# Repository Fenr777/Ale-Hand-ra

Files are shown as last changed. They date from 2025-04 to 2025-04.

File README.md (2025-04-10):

# Ale-HAND-ra: An Open-Source, Low-Cost Humanoid Robotic Hand

**Ale-HAND-ra** is an open-source humanoid robotic hand designed to be affordable, accessible, and highly functional. It leverages digital fabrication techniques like 3D printing to replicate the dexterity and movement of a human hand using low-cost materials. As an open-source initiative, Ale-HAND-ra invites collaboration and customization from the robotics community for educational, prosthetic, or research applications.

<p align="center">
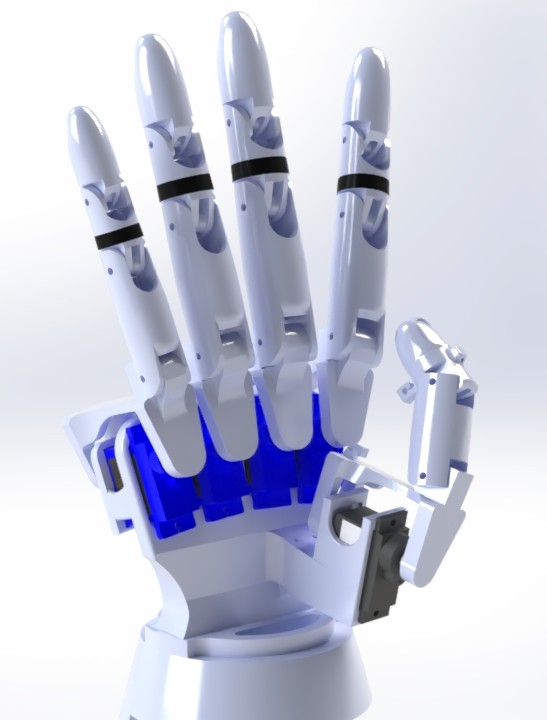
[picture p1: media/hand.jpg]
  
</p>

---

## Table of Contents

- [Ale-HAND-ra: An Open-Source, Low-Cost Humanoid Robotic Hand](#ale-hand-ra-an-open-source-low-cost-humanoid-robotic-hand)
  - [Table of Contents](#table-of-contents)
  - [About the Project](#about-the-project)
  - [Features](#features)
  - [Getting Started](#getting-started)
  - [Estimated Costs](#estimated-costs)
  - [Repository Structure](#repository-structure)
  - [Contributing](#contributing)
  - [License](#license)

---

## About the Project

Ale-HAND-ra addresses the lack of accessible, open-source robotic hands that emulate human functionality. By combining biomechanical analysis with cost-effective 3D printing, this hand achieves 20 degrees of freedom, enabling precise grasping and manipulation of objects of up to 350 grams. Its modular design and use of affordable components—like SG90, EMAX ES08MD II, and MG996R servomotors—make it an ideal platform for hobbyists, students, and researchers.

<p align="center">
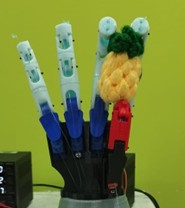
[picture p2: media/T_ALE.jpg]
  
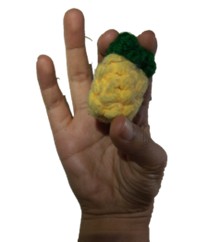
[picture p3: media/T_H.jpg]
  
</p>

---

## Features

- **20 Degrees of Freedom**: Closely mimics human hand biomechanics, supporting flexion, extension, abduction, adduction, and wrist pronation/supination.
- **Modular Design**: Easy to customize, repair, or modify individual components (palm, fingers, forearm).
- **Precise Control**: Powered by an ESP32 microcontroller and PCA9685 PWM module, with wireless control via the Blynk platform.
- **Low-Cost Fabrication**: Built using 3D-printed parts and affordable servomotors, optimized for accessibility.
- **Open-Source**: Fully documented design and code, encouraging community contributions.
  
<p align="center">
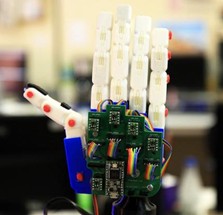
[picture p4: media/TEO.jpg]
  
</p>

---

## Getting Started

To build your own Ale-HAND-ra, follow these steps:

1. **Review the Build Guide**: See [`documentation/build_guide.md`](./documentation/build_guide.md) for detailed assembly instructions.
2. **Gather Materials**: Check the List of Materials in for required components.
3. **3D Print the Parts**: Use the files from [`design_files/ready_to_print_files/`](./design_files/ready_to_print_files) to 3D print all the hand parts.
4. **Assemble the Hand**: Follow the step-by-step instructions in the build guide.
5. **Upload the Code**: Use the Arduino code at [`code/ALEHANDRA.ino`](./code/ALEHANDRA.ino) to test your hand!

**Prerequisites**:
- 3D printer (FDM or SLA recommended, but not necessary)
- Basic electronics skills (soldering, wiring)
- Arduino programming knowledge

<p align="center">
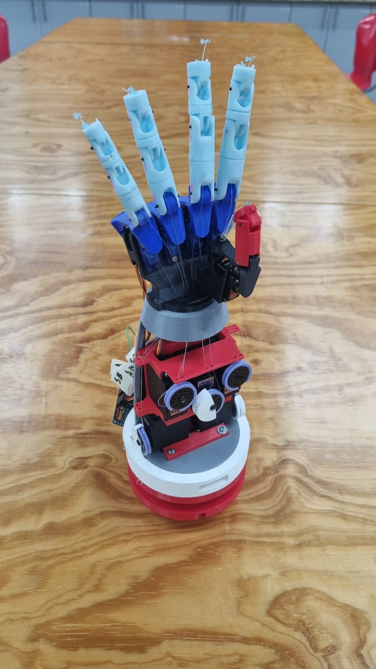
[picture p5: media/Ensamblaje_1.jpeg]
  
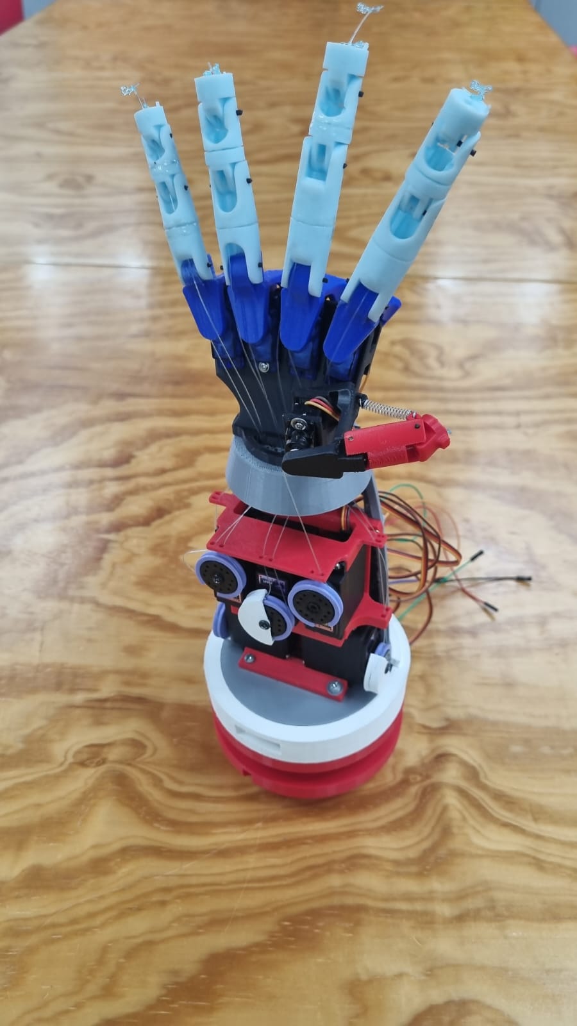
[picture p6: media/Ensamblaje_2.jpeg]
  
</p>

---

## Estimated Costs

Ale-HAND-ra is designed to be cost-effective. Here’s a breakdown of the cost per hand manufactured:

| Description | Quantity | Subtotal ($) | Comments |
|---|---|---|---|
| 3D Printing (Resin) | 264 minutes  | 21.33 | Price per FABLAB UNITEC |
| 3D Printing (PLA) | 210 minutes  | 10.18 | Price per FABLAB UNITEC |
| EMAX ES08MD II Servomotor | 1 | 11.72 | N/A |
| SG90 Servomotors | 4 | 26.67 | N/A |
| MG996R Servomotors | 5 | 58.59 | N/A |
| ESP32 Microcontroller | 1 | 16.97 | N/A |
| PCA9685 Servo Controller | 1 | 10.42 | N/A |
| Dupont Cables (Female-Female, Male-Male, Male-Female) | 1 | 10.10 | N/A |
| Fishing Nylon | 1 | 1.90 | N/A |
| **TOTAL ($)** | | **167.88** | |

---

## Repository Structure

- **`design_files/`**: 3D models for printing and modification.
  - `ready_to_print_files/`: Ready-to-print files.
  - `solidworks/`: Native SolidWorks files.
- **`code/`**: Code for testing hand movement.
- **`documentation/`**: Extra documentation.
- **`media/`**: Visuals for documentation and README.

---

## Contributing

We welcome contributions to enhance Ale-HAND-ra! To get involved:
- Report bugs or suggest features via GitHub Issues.
- Fork the repo and try it out!
- Share your builds or modifications with the community.
- Leave a star if you like our work!

---

## License

This project is licensed under the [MIT License](LICENSE), allowing free use, modification, and distribution with proper attribution.

---

<p align="center">
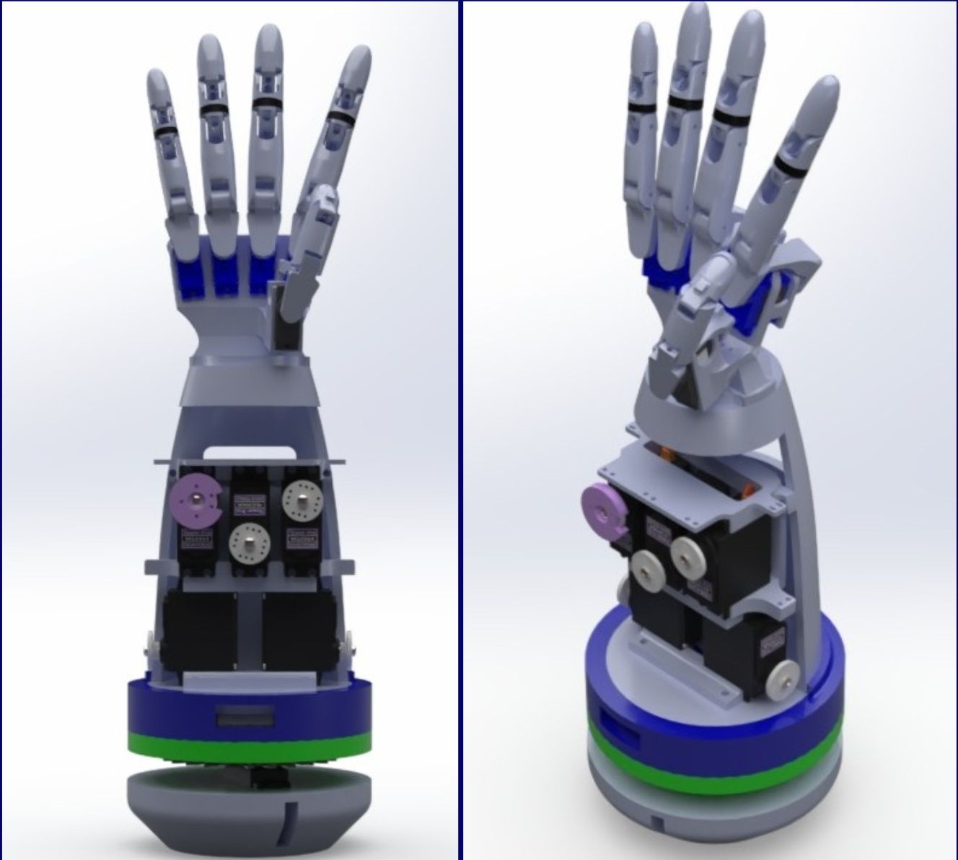
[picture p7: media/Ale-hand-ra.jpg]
  
</p>

*Multiview Ale-HAND-ra*

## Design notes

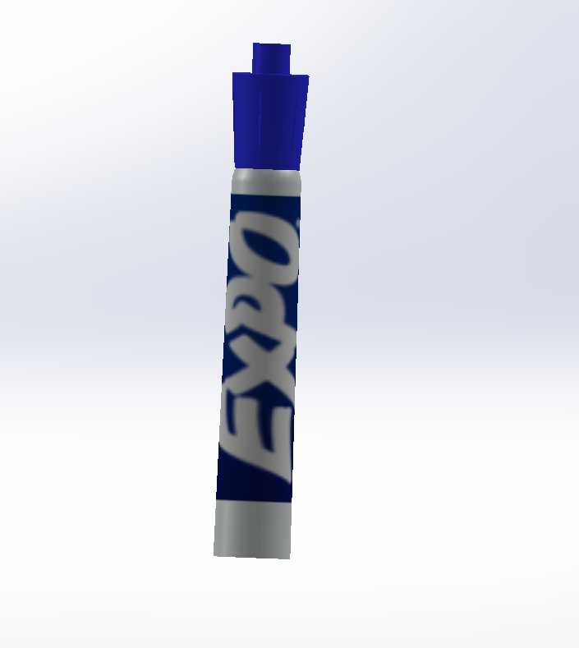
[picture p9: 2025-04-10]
design_files/solidworks/expo-marker-1.snapshot.2/Renderings/Untitled.png

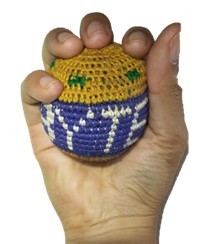
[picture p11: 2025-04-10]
media/EP_H.jpg

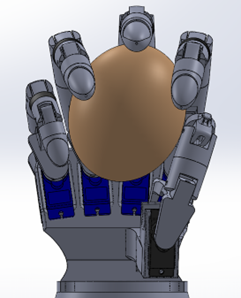
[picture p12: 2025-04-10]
media/E ALE SW.png

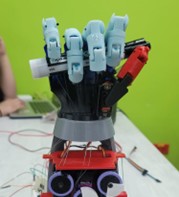
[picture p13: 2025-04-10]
media/DP_ALE.jpg

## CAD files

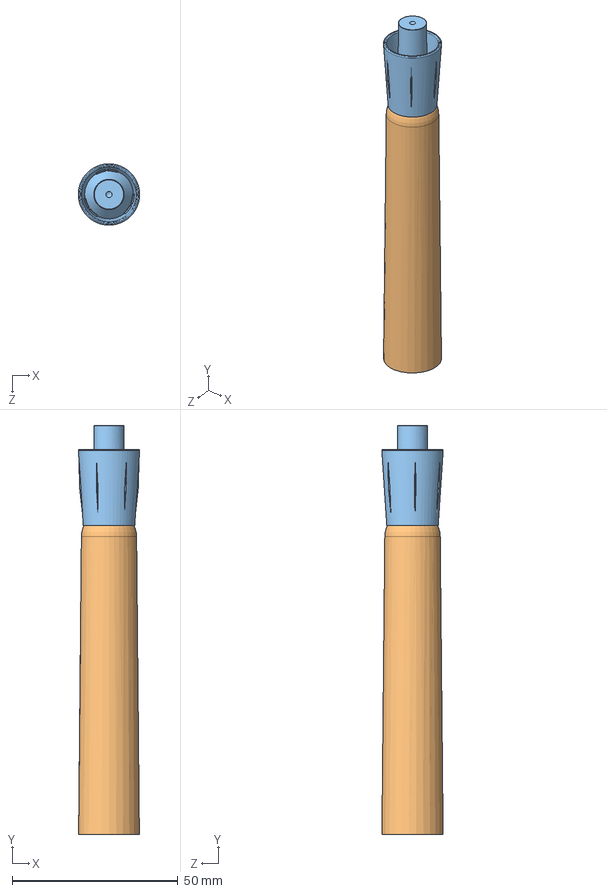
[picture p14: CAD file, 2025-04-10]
design_files/solidworks/expo-marker-1.snapshot.2/EMF.SLDASM
18.5 x 123.5 x 18.5 mm
tip
EARTH
Expo Marker Cap
marker bottom
ink

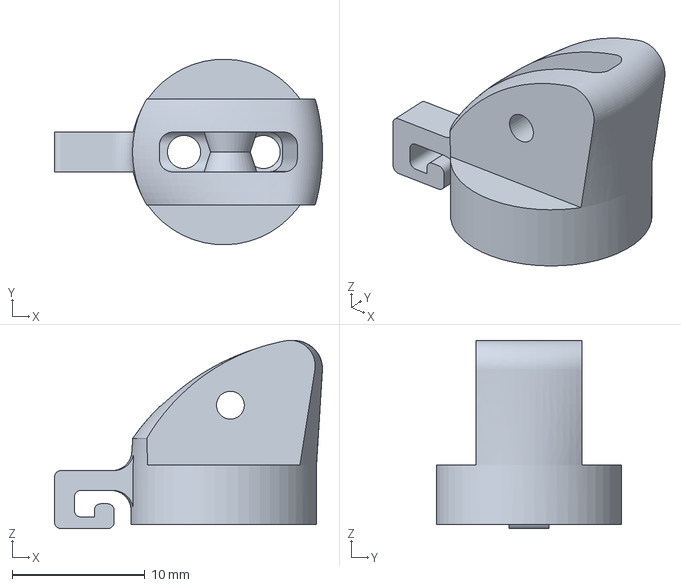
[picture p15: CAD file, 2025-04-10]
design_files/ready_to_print_files/Pulgar_2_FDM.3MF
20.2 x 14.0 x 14.2 mm

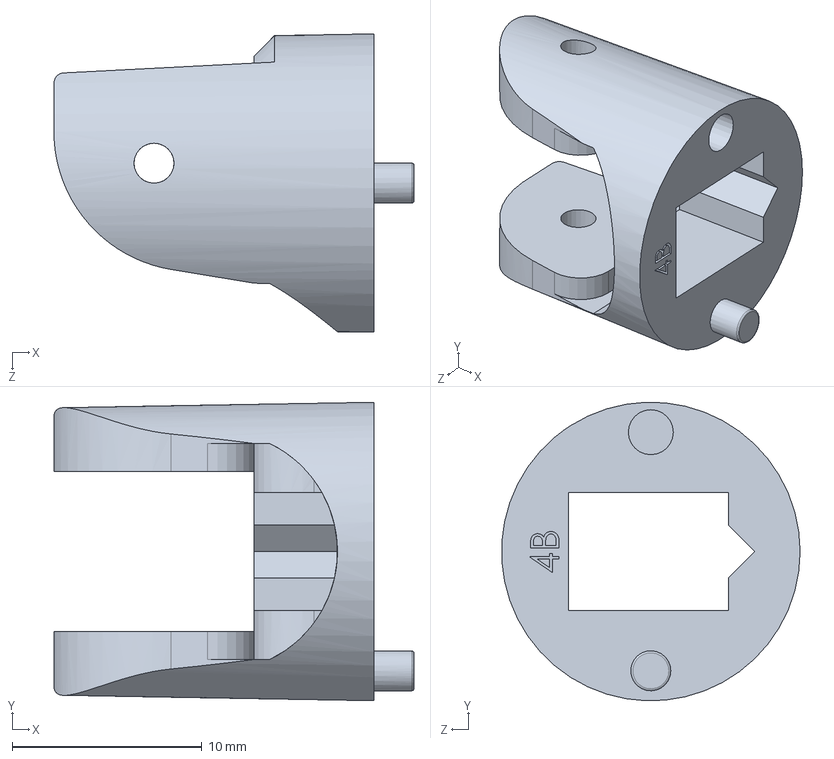
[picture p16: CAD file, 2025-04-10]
design_files/solidworks/DEDO_MEDIO/B Falange 3-6.SLDPRT
19.0 x 15.7 x 15.7 mm

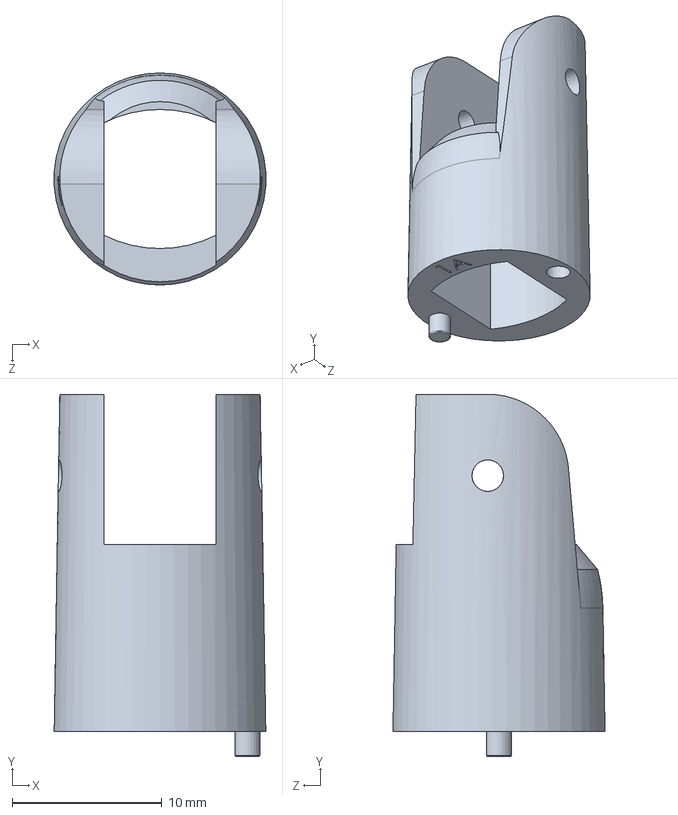
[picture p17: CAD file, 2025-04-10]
design_files/solidworks/DEDO_MEÑIQUE/A Falange 3-4.SLDPRT
14.1 x 24.2 x 14.2 mm

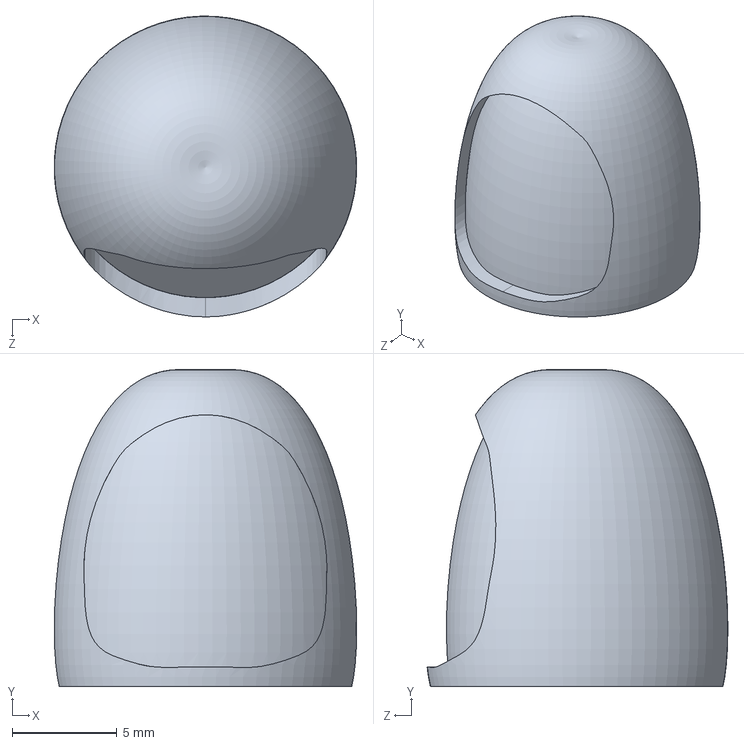
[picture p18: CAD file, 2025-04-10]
design_files/solidworks/DEDO_PULGAR/Uña_pulgar.SLDPRT
14.5 x 15.2 x 14.4 mm

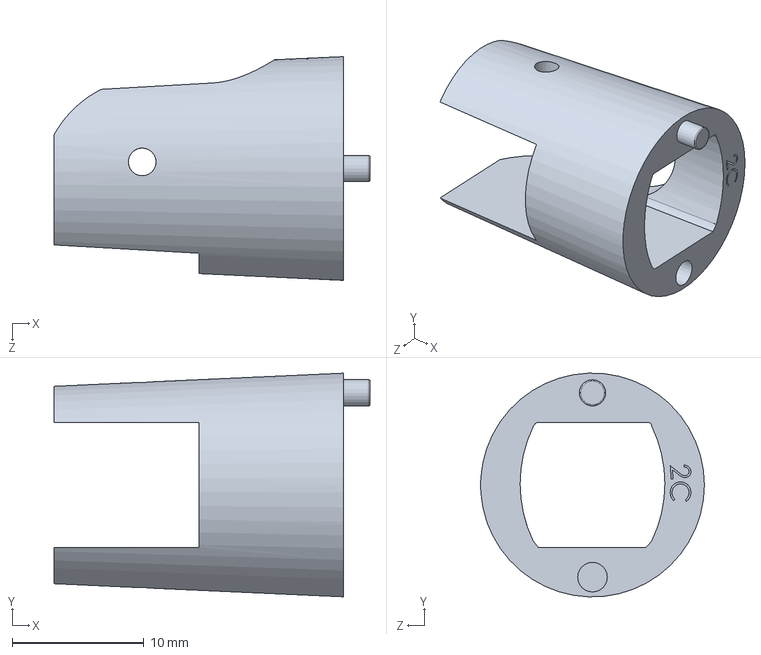
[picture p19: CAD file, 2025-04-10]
design_files/solidworks/DEDOS_ÍNDICE_ANULAR/C Falange 3-3.SLDPRT
24.0 x 17.0 x 17.0 mm

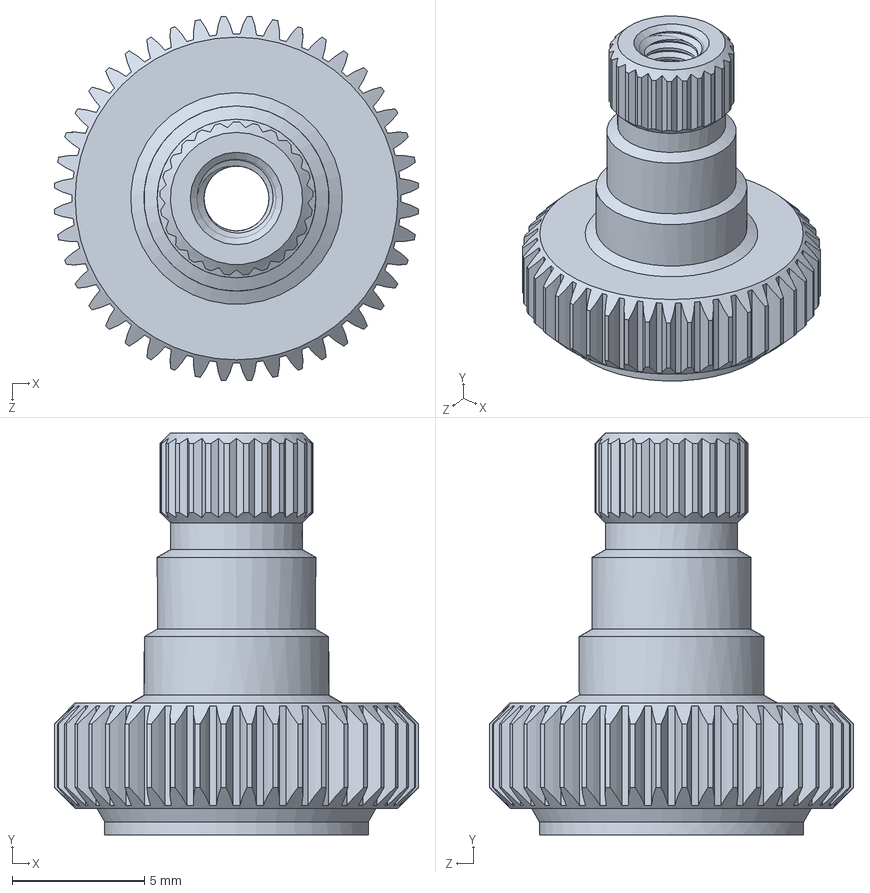
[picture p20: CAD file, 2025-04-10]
design_files/solidworks/mg996r-servo-motor-3.snapshot.16/MG996R Servo Motor/Output Shaft.SLDPRT
13.8 x 15.2 x 13.8 mm

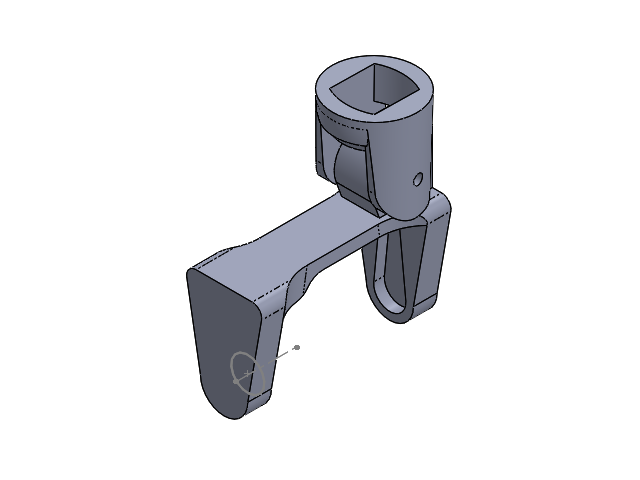
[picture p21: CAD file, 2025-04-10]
design_files/solidworks/DEDO_PULGAR/Ensamble_pulgar.SLDASM
ACOPLE DEDO
falange pulgar

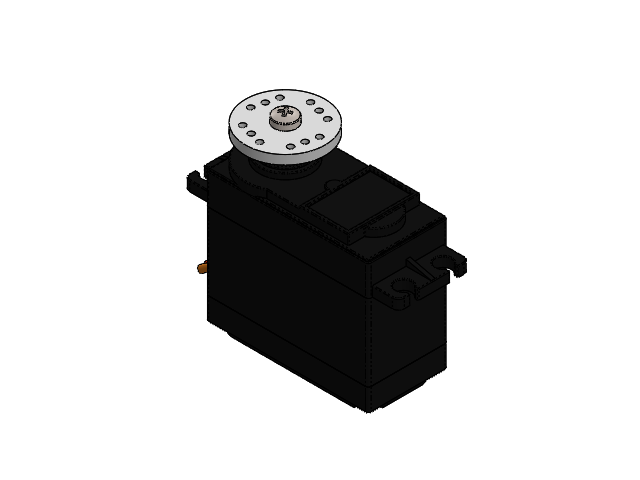
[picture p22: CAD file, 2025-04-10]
design_files/solidworks/MG996R Servo Motor PRUEBA.SLDASM
Case
Output Shaft
Rubber Wire Cable Sleeve
Pan Head Cross Screw M1.6 x 4
Servo Horns
Pan Head Cross Screw M3

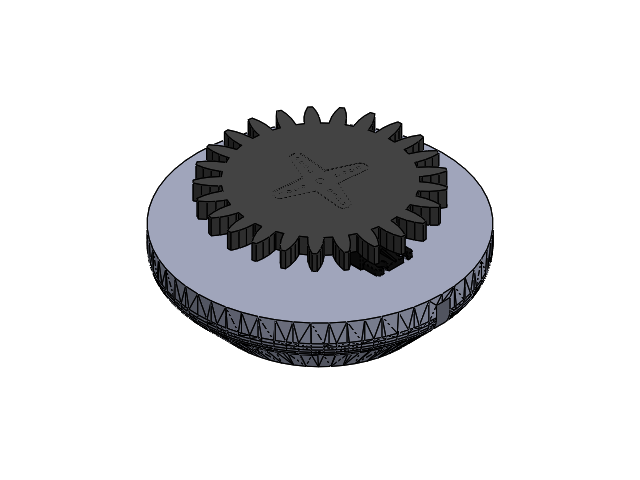
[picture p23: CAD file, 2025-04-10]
design_files/solidworks/Base_Servo_1.SLDASM
Case
Output Shaft
Rubber Wire Cable Sleeve
Pan Head Cross Screw M1.6 x 4
Servo Horns
Base_Servo
Engrane

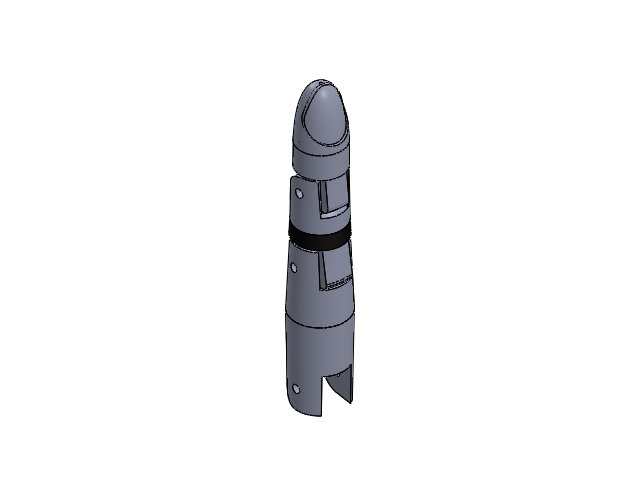
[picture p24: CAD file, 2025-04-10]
design_files/solidworks/DEDO_MEÑIQUE/A_ensamble_meñique.SLDASM
A Falange 3-4
A Falange 3-5
A Falange 3-6
A Falange 3-2
A Falange UÑA
A Falange 3-3

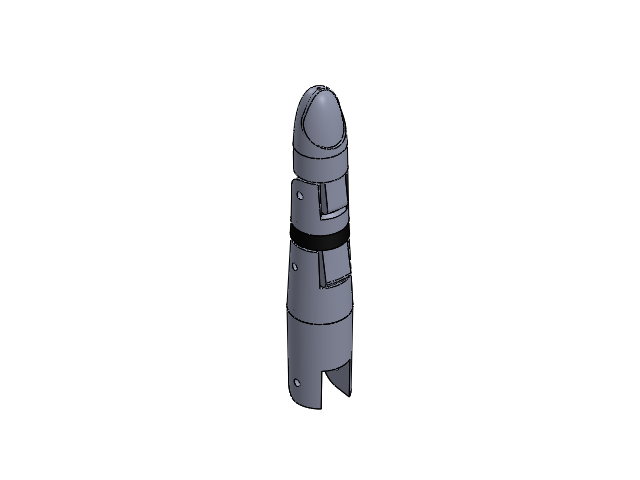
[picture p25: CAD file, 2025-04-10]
design_files/solidworks/DEDOS_ÍNDICE_ANULAR/C_ensamble_índice_anular.SLDASM
C Falange 3-4
C Falange 3-5
C Falange 3-6
C Falange 3-2
C Falange UÑA
C Falange 3-3

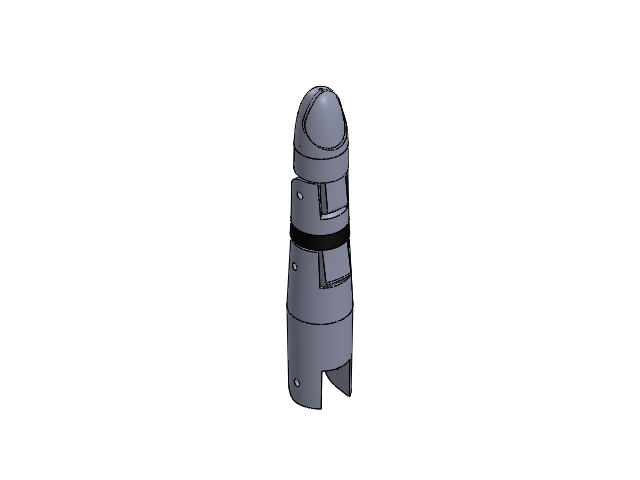
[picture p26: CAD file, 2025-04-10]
design_files/solidworks/DEDO_MEDIO/B_ensamble_medio.SLDASM
B Falange 3-4
B Falange 3-5
B Falange 3-6
B Falange 3-2
B Falange UÑA
B Falange 3-3

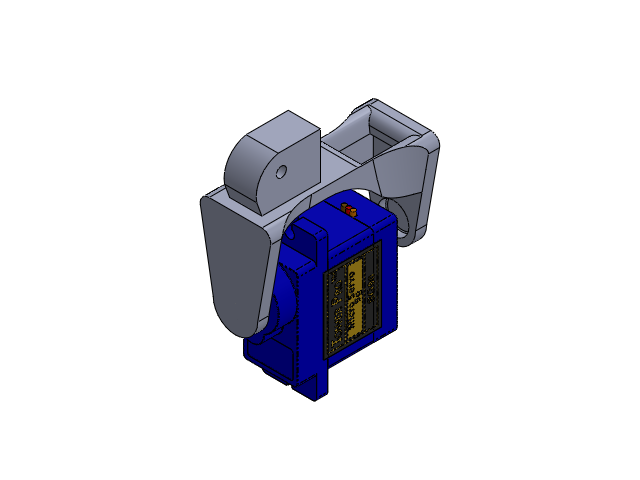
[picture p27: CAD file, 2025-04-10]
design_files/solidworks/PRUEBA 2 SG90.SLDASM
SG90
ACOPLE DEDO este si MEÑIQUE

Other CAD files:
design_files/solidworks/expo-marker-1.snapshot.2/EM-COMPLETED MARKER.SLDASM
design_files/solidworks/MG996R Servo Motor PRUEBA2.SLDASM
design_files/solidworks/Ensable_carcasa_servos.SLDASM
design_files/solidworks/SG90 ACOPLE EMAX.SLDASM
design_files/ready_to_print_files/Acoples_FDM.stl
design_files/ready_to_print_files/Antebrazo_FDM.3MF
design_files/ready_to_print_files/Base_Servo_FDM.STL
design_files/ready_to_print_files/Carcasa_servo_1_FDM.3MF
design_files/ready_to_print_files/Carcasa_servo_2_FDM.3MF
design_files/ready_to_print_files/Engrane_FDM.STL
design_files/ready_to_print_files/Palma_FDM.3MF
design_files/ready_to_print_files/Poleas_Flexion_Extension_FDM.stl
design_files/ready_to_print_files/Pulgar_1_FDM.3MF
design_files/ready_to_print_files/Rotacion_1_FDM.STL
design_files/ready_to_print_files/Rotacion_2_FDM.3MF
design_files/ready_to_print_files/Uña_pulgar_FDM.3MF
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

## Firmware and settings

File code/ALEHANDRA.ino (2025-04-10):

#define BLYNK_TEMPLATE_ID "TMPL2APmbSldI"
#define BLYNK_TEMPLATE_NAME "AleHANDra"
#define BLYNK_AUTH_TOKEN "9k5JiPhQKm--B35W8TbDUBMGI4TEniTc"

#define BLYNK_PRINT Serial
#include <Wire.h>
#include <Adafruit_PWMServoDriver.h>
#include <WiFiClient.h>
#include <BlynkSimpleEsp32.h>

Adafruit_PWMServoDriver pca = Adafruit_PWMServoDriver(0x40);

#define servoMIN 125
#define servoMAX 600

char auth[] = "9k5JiPhQKm--B35W8TbDUBMGI4TEniTc";
char ssid[] = "Redmi Note 12";
char pass[] = "Hillary01";

void setup() {
  Serial.begin(115200);
  Wire.begin(21, 22);
  pca.begin();
  pca.setPWMFreq(60);
  Blynk.begin(auth, ssid, pass, "blynk.cloud", 80);
  Serial.println("Blynk conectado, listo para recibir comandos.");
}

void moverServo(int numServo, int valor, int minGrados, int maxGrados) {
  int posPWM = map(valor, minGrados, maxGrados, servoMIN, servoMAX);
  Serial.print("Servo "); Serial.print(numServo);
  Serial.print(" -> Grado: "); Serial.print(valor);
  Serial.print(" -> PWM: "); Serial.println(posPWM);
  pca.setPWM(numServo, 0, posPWM);
}

// Servos de 0 a 20 grados (V0-V3)
BLYNK_WRITE(V0) { moverServo(0, param.asInt(), 0, 20); }
BLYNK_WRITE(V1) { moverServo(1, param.asInt(), 0, 20); }
BLYNK_WRITE(V2) { moverServo(2, param.asInt(), 0, 20); }
BLYNK_WRITE(V3) { moverServo(3, param.asInt(), 0, 20); }

// Servo de 0 a 90 grados (V4)
BLYNK_WRITE(V4) { moverServo(4, param.asInt(), 0, 90); }

// Servos de 0 a 180 grados (V5-V10)
BLYNK_WRITE(V5) { moverServo(5, param.asInt(), 0, 180); }
BLYNK_WRITE(V6) { moverServo(6, param.asInt(), 0, 180); }
BLYNK_WRITE(V7) { moverServo(7, param.asInt(), 0, 180); }
BLYNK_WRITE(V8) { moverServo(8, param.asInt(), 0, 180); }
BLYNK_WRITE(V9) { moverServo(9, param.asInt(), 0, 180); }
BLYNK_WRITE(V10) { moverServo(10, param.asInt(), 0, 180); }

void loop() {
  Blynk.run();
}
